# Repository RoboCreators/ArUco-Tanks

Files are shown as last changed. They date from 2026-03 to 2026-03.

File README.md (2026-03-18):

# ArUco Tanks

Ein kamerabasiertes Laser-Tag-Spielsystem mit ferngesteuerten ESP32-Fahrzeugen und markerbasierter Objekterkennung über ArUco-Marker.

Das Projekt wurde im Rahmen eines Studienprojekts an der **HTWK Leipzig** entwickelt.  
Die Treffererkennung erfolgt softwareseitig über eine externe Kamera, Computer Vision und eine zentrale Spiellogik auf dem Laptop.

<p align="center">
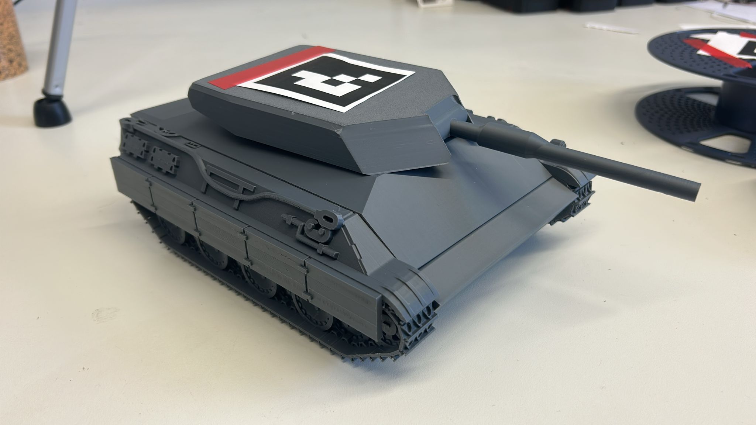
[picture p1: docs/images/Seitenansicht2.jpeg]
  
</p>

---

## Inhaltsverzeichnis

- [Zielsetzung](#zielsetzung)
- [Systemübersicht](#systemübersicht)
- [Hardwareübersicht](#hardwareübersicht)
- [Software- & Repository-Struktur](#software--repository-struktur)
- [Getting Started](#getting-started)
- [Projektkontext](#projektkontext)
- [Nützliche Ressourcen](#nützliche-ressourcen)
- [Weiterentwicklung](#weiterentwicklung)
- [Lizenz](#lizenz)

---

## Zielsetzung

Ziel des Projekts ist die Entwicklung eines spielbaren Mehrkomponentensystems aus:

- zwei ferngesteuerten Fahrzeugen
- einer externen Kamerainstanz zur Objekterkennung
- einer zentralen Spielumgebung auf dem Laptop
- einer softwarebasierten Treffererkennung mit ArUco-Markern

Dabei werden mechanische Konstruktion, Mikrocontrollersteuerung, drahtlose Kommunikation, Kamerakalibrierung und Bildverarbeitung in einem Gesamtsystem kombiniert.

---

## Systemübersicht

Das Spielsystem basiert auf einer **markerbasierten visuellen Objekterkennung**.

- Eine externe Kamera erfasst das Spielfeld.
- Die Fahrzeuge tragen ArUco-Marker zur Positions- und Orientierungserkennung.
- Ein Laptop übernimmt die Bildverarbeitung und Spiellogik.
- Die Kommunikation mit den Fahrzeugen erfolgt drahtlos über ESP32-basierte Steuerung.
- Treffer werden nicht durch physische Sensoren, sondern über die geometrische Auswertung von Schusslinie und Hitbox in der Spielumgebung erkannt.

---

## Hardwareübersicht

### Fahrzeuge

- ESP32 Dev Board  
- LM2596 Step-Down Converter
- 2× DC Getriebemotoren 
- 28BYJ-48 Schrittmotor  
- WS-25514 Motorcontroller  
- ULN2003 Treibermodul  
- 7.4 V Li-Ion Akku  
- Hauptschalter (DPDT)
- Reset-Button

### Externe Komponenten

- Kamera zur Erfassung des Spielfelds
- Laptop zur Bildverarbeitung und Spielsteuerung
- Gamepad zur Fahrzeugsteuerung

### Markerbasiertes Tracking

- ArUco-Marker zur Identifikation der Fahrzeuge
- Kamerakalibrierung zur präziseren Positionsbestimmung
- Berechnung von Position, Orientierung und Schussrichtung im Kamerabild

### Benötigte Verbindungselemente

Für den Aufbau werden zusätzlich folgende Schrauben, Muttern und Gewindeeinsätze benötigt:

- **M2:** 5× M2×6 mm, 2× M2×13 mm, 6× Muttern, 1× Heatset-Insert
- **M2.5:** 10× M2,5×10 mm, 10× Muttern
- **M3:** 18× M3×6 mm, 2× M3×8 mm, 1× M3×10 mm, 10× Muttern, 7× Heatset-Inserts
- **M4:** 2× M4×8 mm, 2× Heatset-Inserts
  
---

## Software & Repository-Struktur

Dieses Repository enthält die zentralen Software- und CAD-Dateien des Projekts.

### CAD

`Baugruppe ArUcoTank`

- Konstruktionsdaten der Fahrzeugkomponenten
- Gehäuse-, Turm- und Halterungsstrukturen
- Grundlage für mechanischen Aufbau und Anpassungen

### Arduino-Code

`Arduino_Steuerungscode.ino`

- Fahransteuerung der Fahrzeuge
- Verarbeitung der Steuerbefehle
- Kommunikation mit der Spielumgebung
- Ansteuerung der Fahrzeugfunktionen über den ESP32

### Jupyter-Notebooks

`01_marker_and_calibration.ipynb`

- Erstellung und Test von ArUco-Markern
- Kamerakalibrierung
- Vorbereitung der markerbasierten Positionsbestimmung

`02_esp32_connection.ipynb`

- Verbindungsaufbau zwischen Laptop und Fahrzeugen
- Kommunikationslogik
- Test der Netzwerkverbindung

`03_detection_and_game_logic.ipynb`

- Objekterkennung mit Kamera
- Bestimmung von Fahrzeugposition und Orientierung
- Trefferlogik, Schussauswertung und Spielmechanik

---

## Getting Started

Das zugehörige Git-Repository enthält neben dem Quellcode auch die mechanische Konstruktion, eine Montageanleitung sowie die Notebooks zur Spielumgebung und Kamerakalibrierung.

Die Montageanleitung befindet sich im Ordner docs.

### Voraussetzungen

Benötigt werden unter anderem:

- Python 3.x
- Jupyter Notebook
- OpenCV mit ArUco-Unterstützung
- NumPy
- ein ESP32-basiertes Fahrzeug
- eine geeignete Kamera
- optional ein Gamepad zur Steuerung

### Empfohlene Reihenfolge

1. ArUco-Marker erzeugen und Kamera kalibrieren  
2. Verbindung zum ESP32 testen  
3. Detektion und Spielumgebung starten  
4. Fahrzeuge im Kamerabild erfassen und Spiel testen  

---

## Projektkontext

Das Projekt entstand im Rahmen des Moduls  
**„Ausgewählte Themen der Automatisierungstechnik“**  
an der **HTWK Leipzig**.

Im Fokus standen insbesondere die Verknüpfung von:

- integrierte Steuerung
- drahtloser Kommunikation
- Computer Vision
- spielbezogener Systemintegration
- iterativer praktischer Entwicklung

---

## Nützliche Ressourcen

### OpenCV / ArUco

- OpenCV Dokumentation
- ArUco Marker Detection
- Kamerakalibrierung mit OpenCV

### ESP32

- ESP32 Dokumentation
- Arduino IDE / ESP32 Board Support

### Python / Notebook-Umgebung

- Jupyter Dokumentation
- NumPy Dokumentation

---

## Weiterentwicklung

Mögliche Erweiterungen des Systems:

- mehrere Kameras zur besseren Spielfeldabdeckung
- autonome Fahrfunktionen
- Erweiterung auf mehr als zwei Fahrzeuge
- verbesserte Benutzeroberfläche für Spielstatus und Punkteanzeige
- optimierte Netzwerkkommunikation und Synchronisation

---

## Projektteam

- Robert B.
- Hieu D.
- Jonas W.

## Lizenz

Dieses Projekt steht unter der **MIT License**.

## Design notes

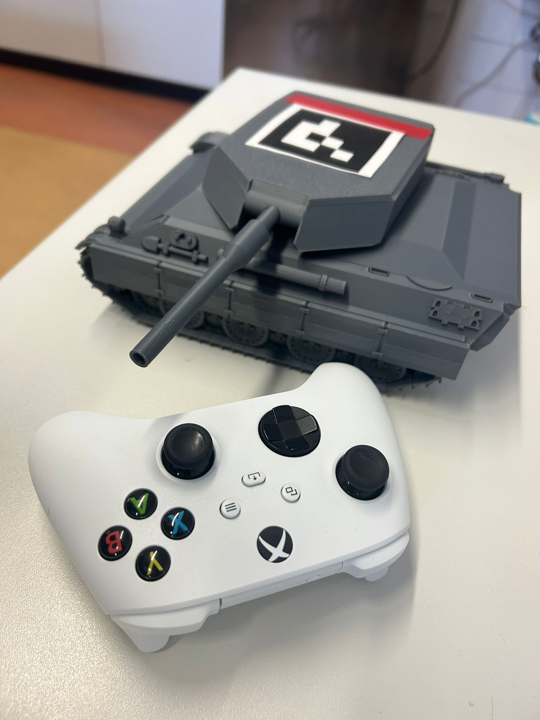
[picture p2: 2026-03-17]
docs/images/Panzer_Gamepad.jpeg

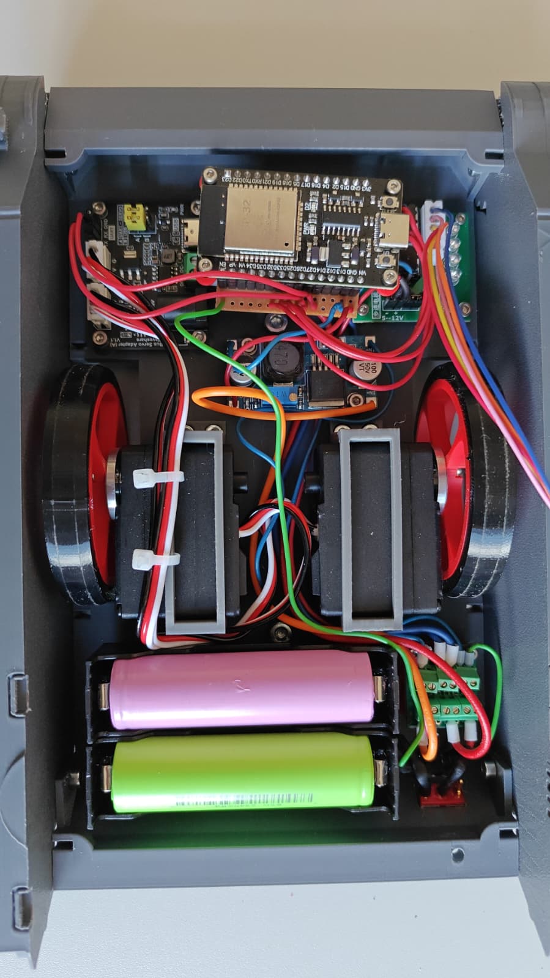
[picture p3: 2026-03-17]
docs/images/Innenraum.jpeg

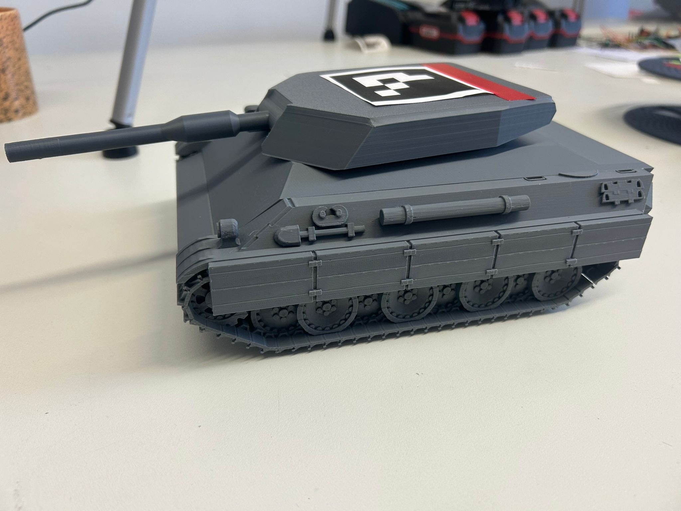
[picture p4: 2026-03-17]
docs/images/Seitenansicht.jpeg

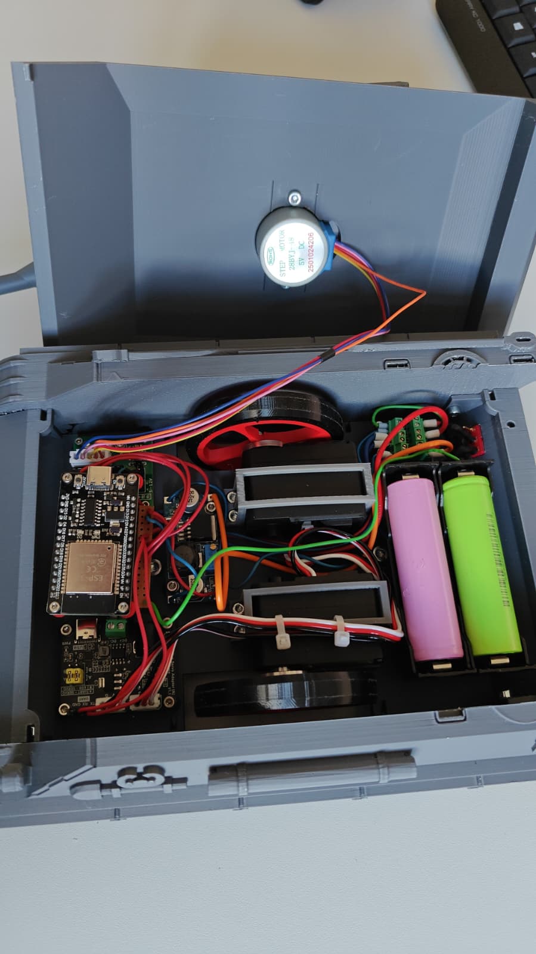
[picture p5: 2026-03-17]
docs/images/offener_Deckel.jpeg

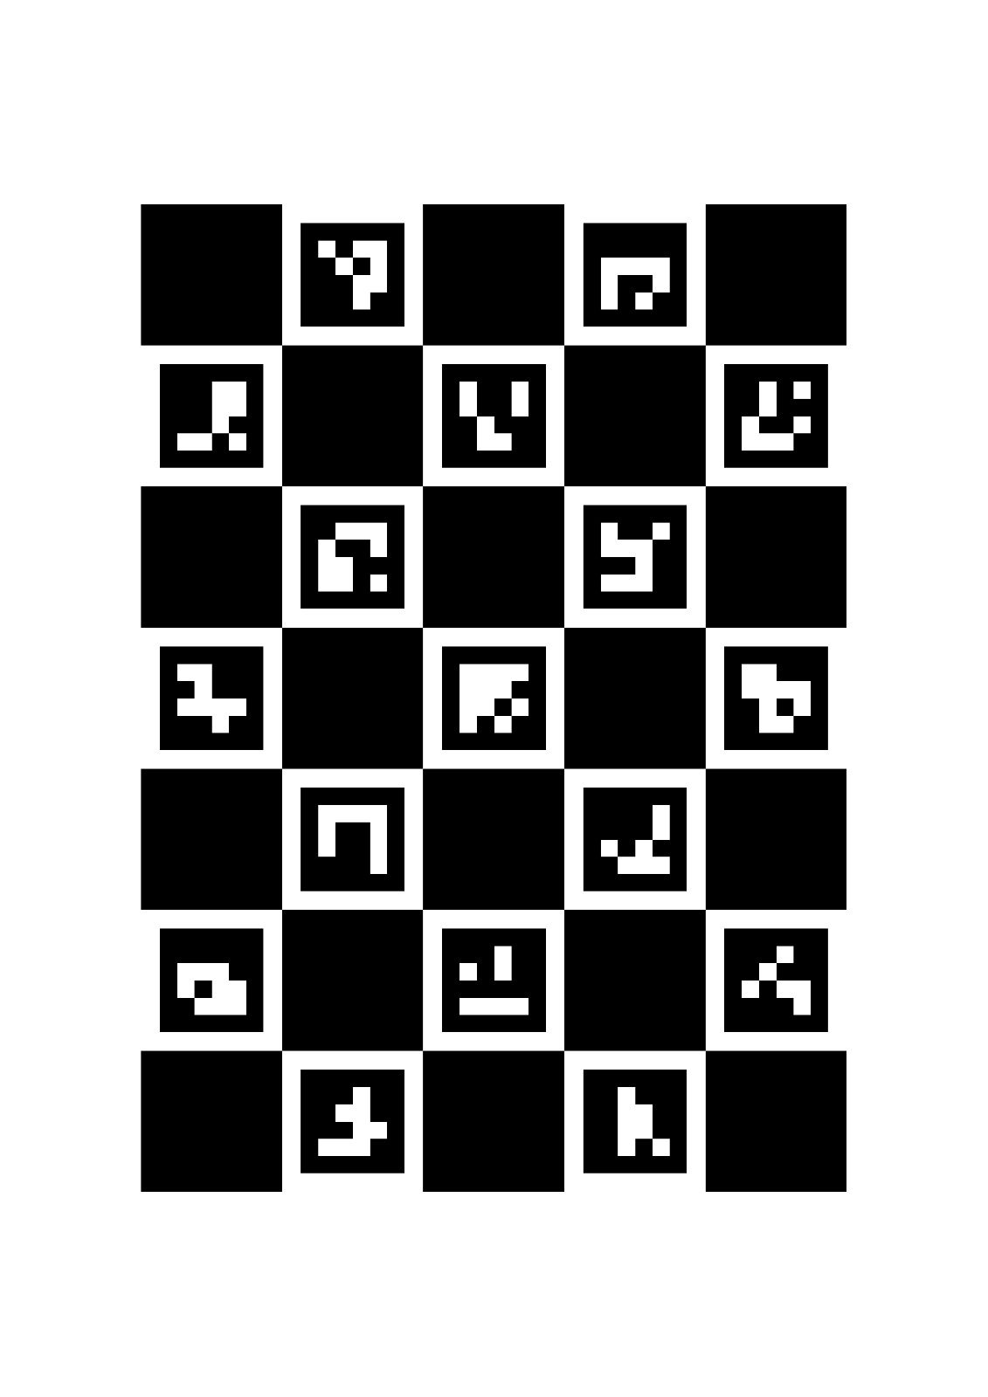
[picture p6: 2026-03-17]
docs/images/ArUco-Board.jpeg

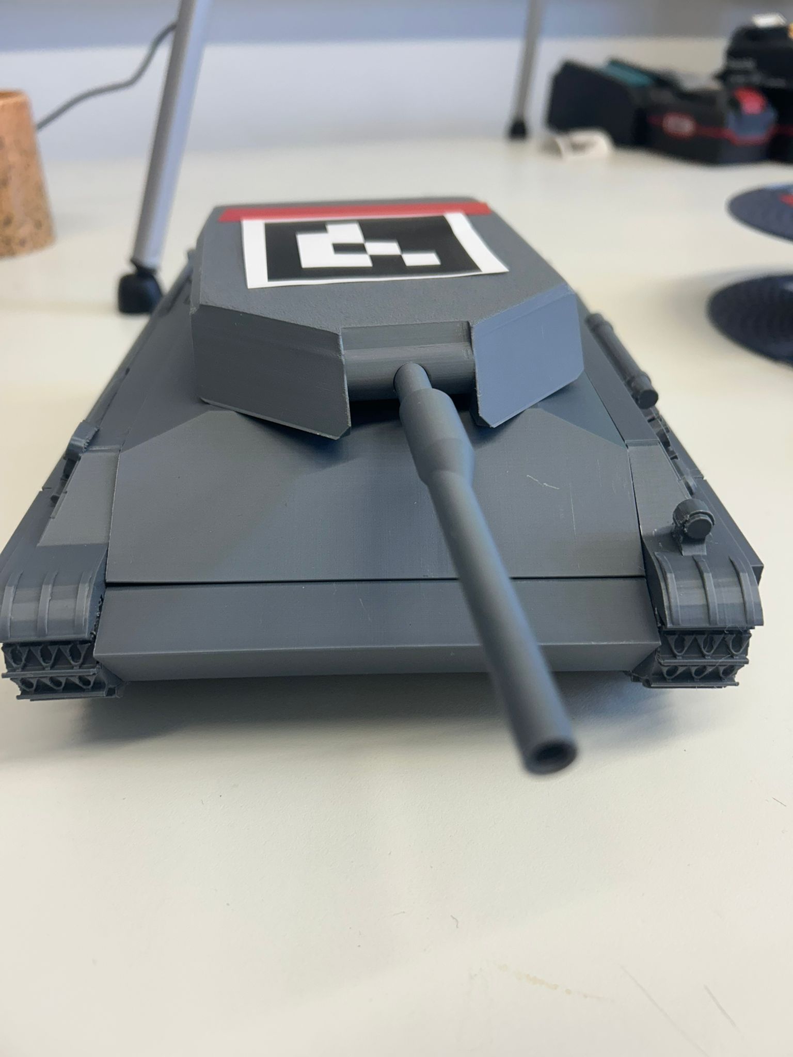
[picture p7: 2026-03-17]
docs/images/Frontansicht.jpeg

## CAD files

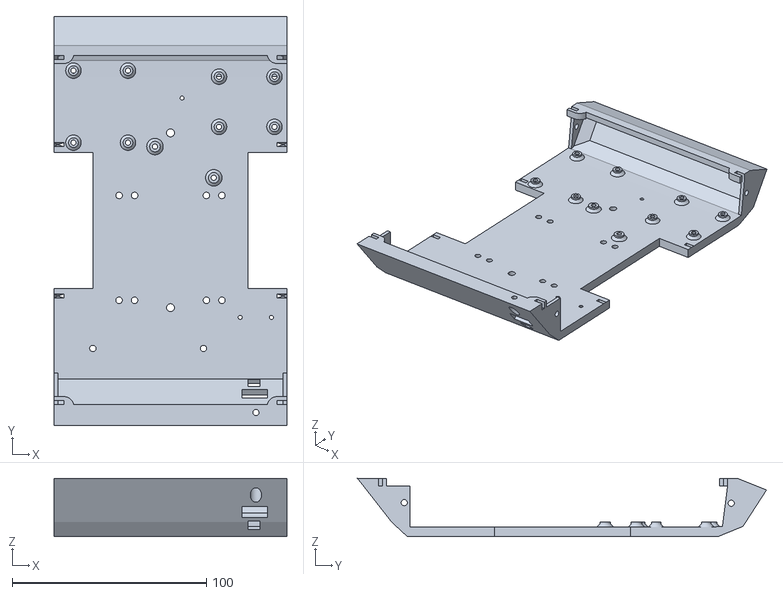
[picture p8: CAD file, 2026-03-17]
STL-Dateien/Gehäuseunterteil.stl
120.0 x 210.7 x 30.0

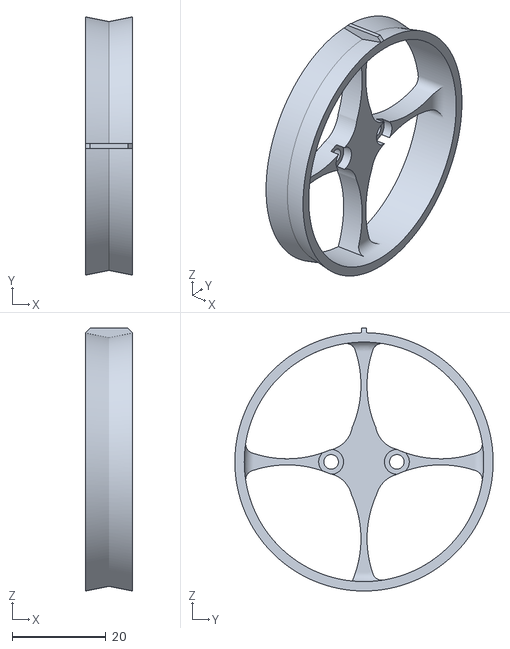
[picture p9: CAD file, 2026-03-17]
STL-Dateien/Rad.stl
10.0 x 55.0 x 56.0

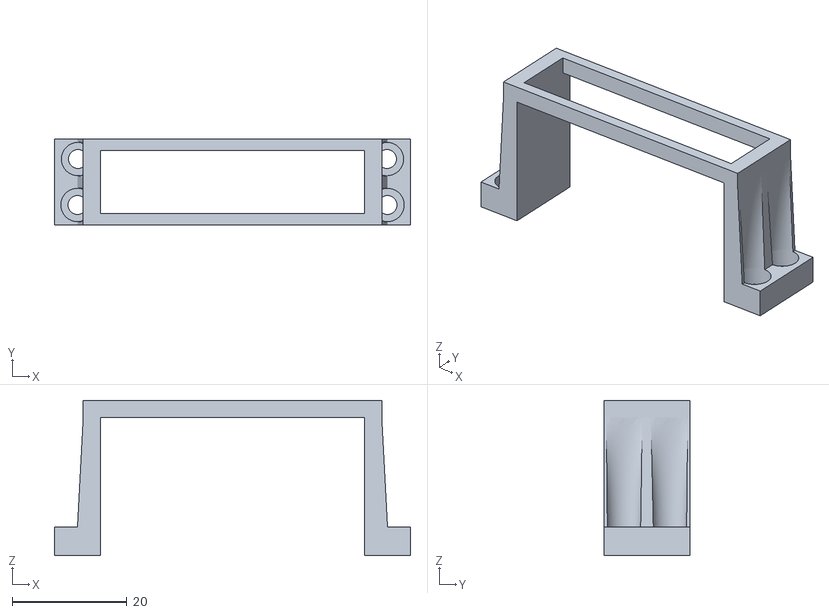
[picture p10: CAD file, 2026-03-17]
STL-Dateien/Servoklemme.stl
62.0 x 15.0 x 27.0

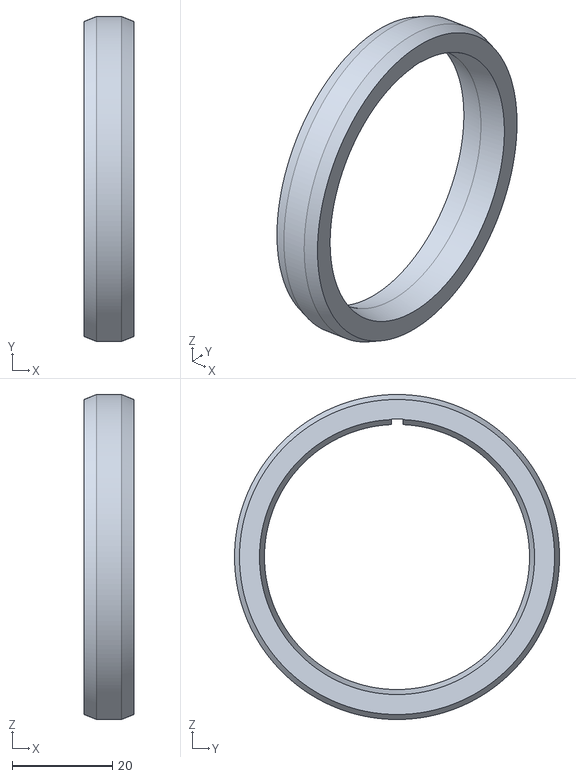
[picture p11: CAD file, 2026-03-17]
STL-Dateien/Reifen.stl
10.0 x 65.0 x 65.0

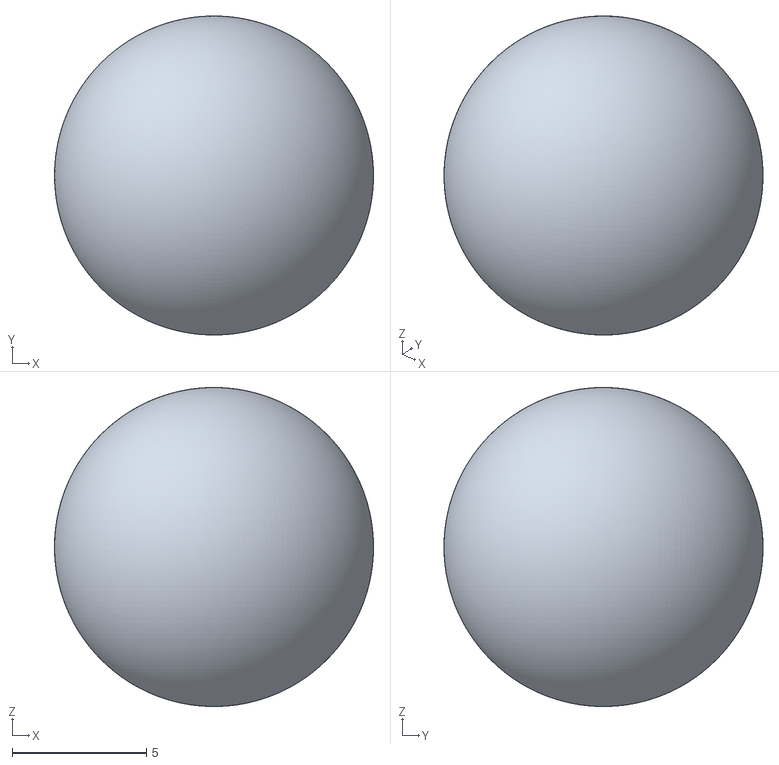
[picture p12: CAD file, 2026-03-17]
STL-Dateien/Kugel.stl
11.9 x 11.9 x 11.9

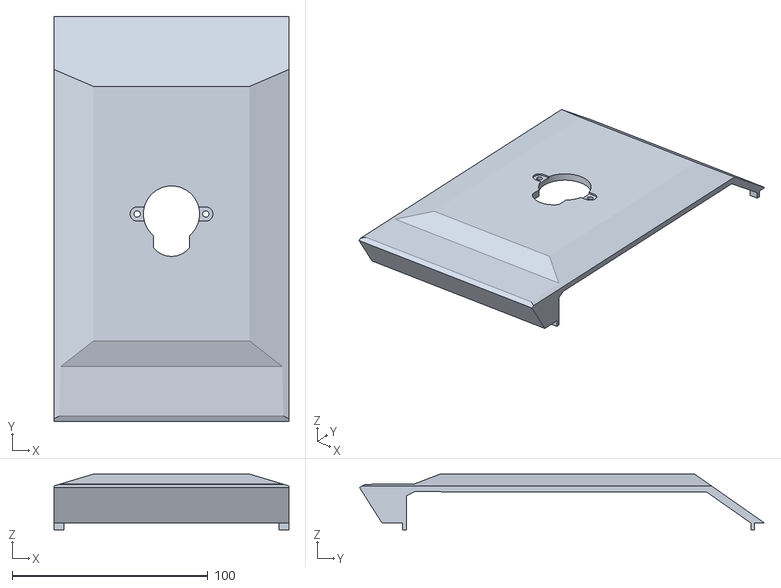
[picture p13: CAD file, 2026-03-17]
STL-Dateien/Gehäuseoberteil.stl
120.0 x 207.1 x 28.5

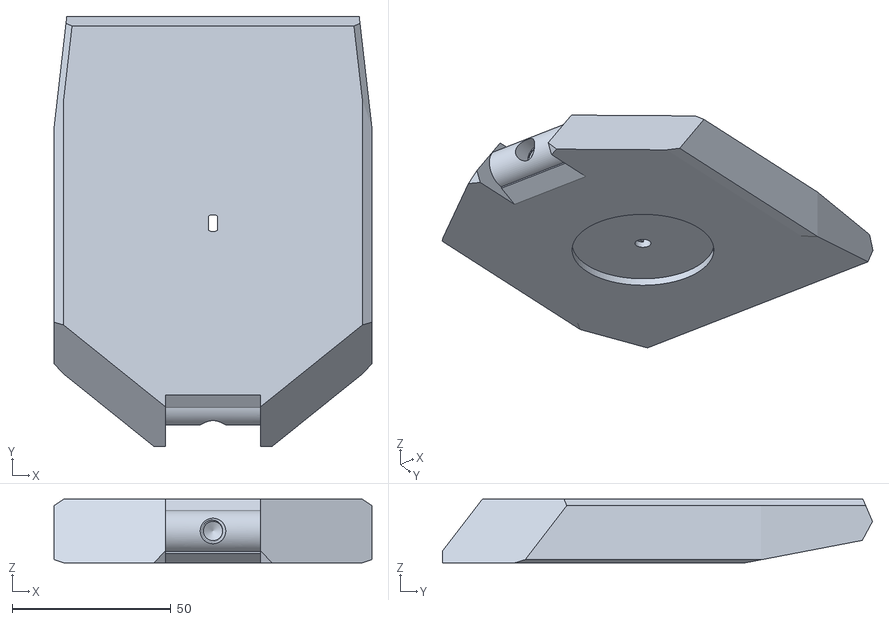
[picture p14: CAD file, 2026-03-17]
STL-Dateien/Panzerturm.stl
100.0 x 135.2 x 20.0

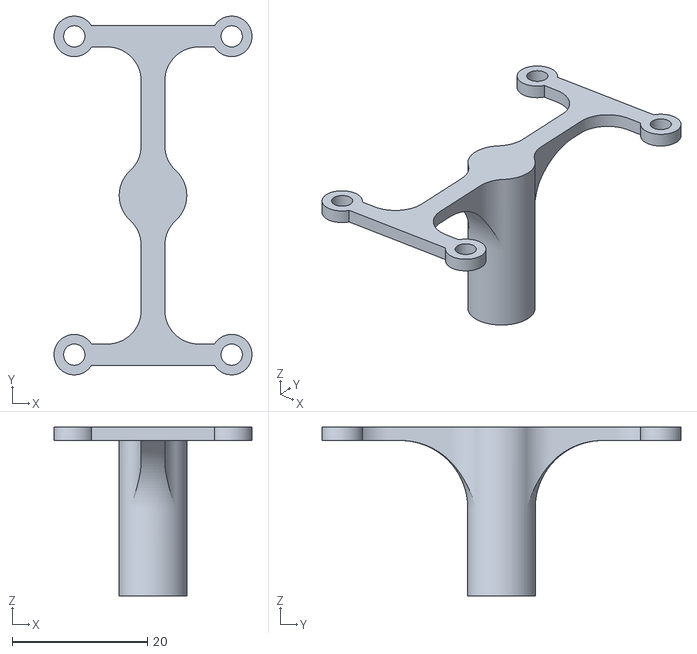
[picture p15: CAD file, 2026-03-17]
STL-Dateien/ESP32 Halter.stl
29.3 x 53.1 x 25.0

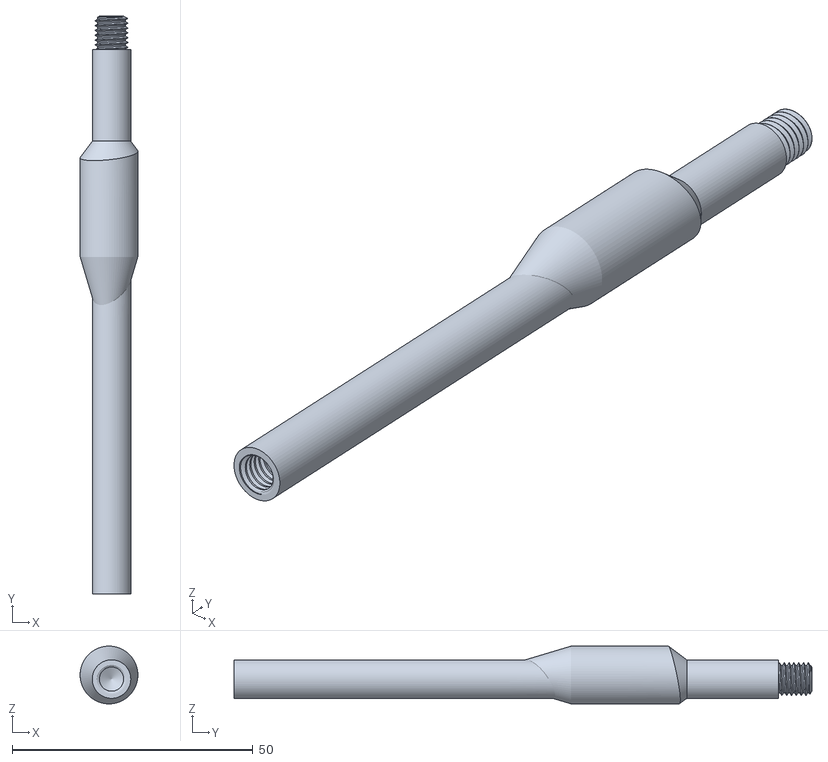
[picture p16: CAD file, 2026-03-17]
STL-Dateien/Kanone.stl
12.0 x 120.0 x 12.0

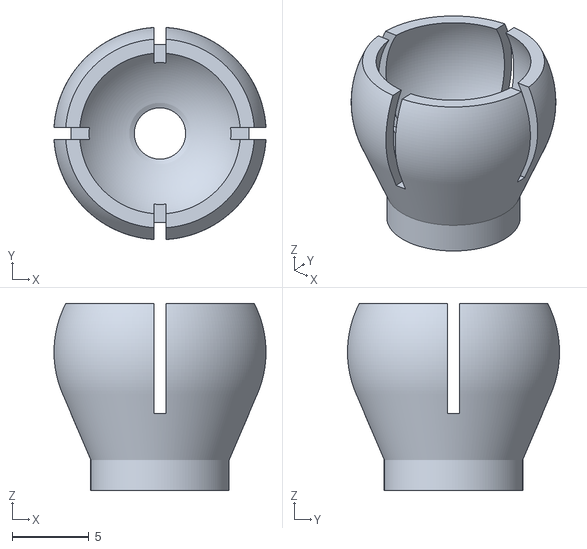
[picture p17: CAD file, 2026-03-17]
STL-Dateien/Kugelhalter.stl
13.8 x 13.8 x 12.2

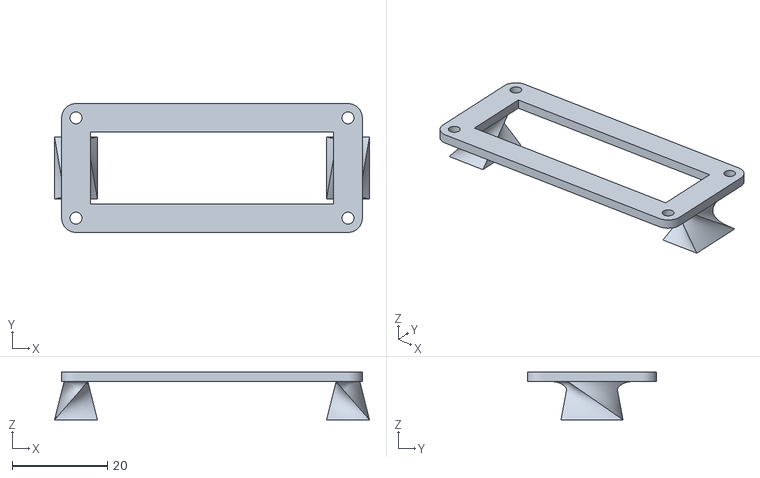
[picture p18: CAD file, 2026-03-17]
STL-Dateien/Batteriehalter.stl
66.0 x 27.0 x 10.0

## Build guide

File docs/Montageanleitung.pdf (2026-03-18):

15.03.2026

Montageanleitung ArUcoTank

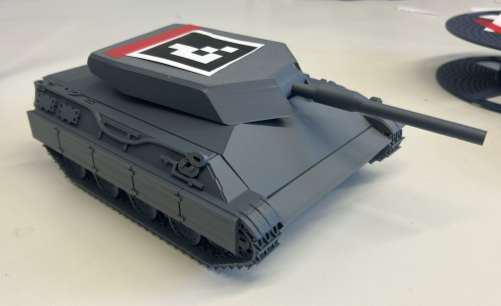
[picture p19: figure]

Alle Grundlochbohrungen werden mit den zugehörigen Heatset-inserts bei einer Lötkolbentemperatur von ca. 250°C bestückt.

Zunächst werden die Kugelhalter mit M3-Schrauben am Unterteil befestigt. Anschließend wird das ESP-Dev-Board mit M2-Schrauben am dafür vorgesehenen Halter montiert.

Im nächsten Schritt werden die Module auf die vorgesehenen Bohrungen auf die Noppen des Gehäuseunterteils aufgelegt und festgeschraubt: Hierzu zählen das ESP-Dev-Board mit Halter, der Bus-Servo-Treiber, der Schrittmotor-Treiber, der Step-Down-Wandler, die selbstgebaute Platine mit Anschlussklemmen.

Für die Befestigung des ESP-Dev-Boards mit Halter, der Platine mit Anschlussklemmen sowie der Step-Down-Wandler werden M2-Schrauben mit Muttern verwendet. Alle übrigen Module werden mit M3-Schrauben und Muttern befestigt.

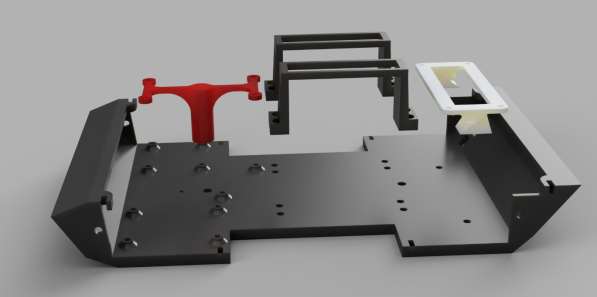
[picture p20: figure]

15.03.2026

Die zwei Reifen werden, formschlüssig mit der Nut, auf die Räder aufgezogen und an die Servomotoren geschraubt. Die Servomotoren wiederum mit den zwei Servoklemmen auf dem Gehäuseunterteil mittig befestigen.

Danach wird der Schalter und der mechanischer Taster in die vorgesehenen Einkerbungen am Gehäuseunterteil eingesetzt. Anschließend werden die beiden Panzerketten an den Eckwänden des Unterteils mit M3-Schrauben befestigt. Die Batteriehalterung wird mit M3-Schrauben auf der Hinterseite des Unterteils verschraubt und mit zwei 18650 Li-Ion Akkus bestückt.

Der Schrittmotor wird von oben durch das Gehäuseoberteil geführt und von unten mit 2 M3-Schrauben und Muttern fixiert. Die Kanone wird per Außengewinde und Passung in den Turm geschraubt und beides auf die Abtriebswelle des Schrittmotors gesteckt.

Abschließend wird das Oberteil mithilfe der vorgesehenen Einkerbungen auf dem Unterteil positioniert und mit einer Schraube an der Hinterseite fixiert. Zur Erkennung per ComputerVision kann ein ArUco-Marker auf die Turmoberseite geklebt werden.

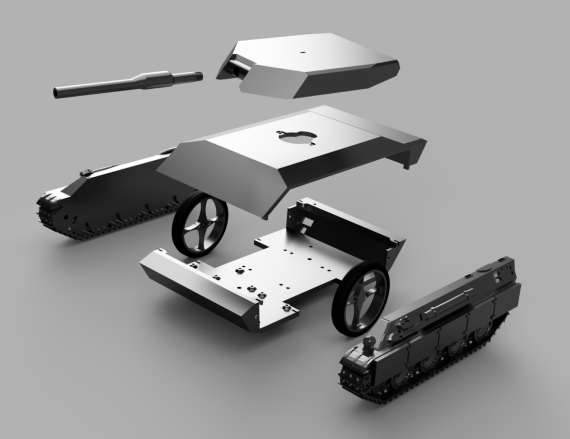
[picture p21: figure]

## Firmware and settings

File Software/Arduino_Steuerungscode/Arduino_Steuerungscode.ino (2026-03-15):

#include <WiFi.h>
#include <WiFiUdp.h>
#include <SCServo.h>

#define S_RXD 14
#define S_TXD 27

// -------------------- WLAN --------------------
const char* WIFI_SSID = "XXX"; //Hotsot-Name
const char* WIFI_PASS = "XXX"; //Hotspot-Passwort

WiFiUDP Udp;
const uint16_t RX_PORT = 4210;

// -------------------- Protokoll --------------------
const uint8_t MAGIC   = 0xA7;
const uint8_t VERSION = 1;
const uint8_t TANK_ID = 1;

// -------------------- Failsafe --------------------
const uint32_t FAILSAFE_MS = 300;
uint32_t lastPacketMs = 0;

// -------------------- Servo --------------------
SMS_STS st;
byte ID[2];

// -------------------- Stepper --------------------
int IN1 = 25;
int IN2 = 33;
int IN3 = 32;
int IN4 = 26;

// -------------------- Empfangenes Steuerkommando --------------------
int16_t axisY  = 0;   // vor/zurück
int16_t axisX  = 0;   // links/rechts fahren
int16_t axisRX = 0;   // Turm

#pragma pack(push, 1)
struct CtrlPacket {
  uint8_t magic;
  uint8_t version;
  uint8_t tank_id;
  uint8_t seq;
  int16_t axisY_be;
  int16_t axisX_be;
  int16_t axisRX_be;
};
#pragma pack(pop)

static_assert(sizeof(CtrlPacket) == 10, "Packet size mismatch");

// ------------------------------------------------------------
// Big-Endian -> ESP32-Format umwandeln
// ------------------------------------------------------------
int16_t swap16(int16_t v) {
  uint16_t u = (uint16_t)v;
  u = (u >> 8) | (u << 8);
  return (int16_t)u;
}

// ------------------------------------------------------------
// Hilfsfunktion: alles stoppen
// ------------------------------------------------------------
void stopAll() {
  // Stepper aus
  digitalWrite(IN1, LOW);
  digitalWrite(IN2, LOW);
  digitalWrite(IN3, LOW);
  digitalWrite(IN4, LOW);

  // Servos stoppen
  st.WriteSpe(1, 0);
  st.WriteSpe(2, 0);
}

// ------------------------------------------------------------
// UDP-Paket lesen
// ------------------------------------------------------------
bool readUdpPacket() {
  int len = Udp.parsePacket();
  if (len <= 0) return false;

  if (len != sizeof(CtrlPacket)) {
    while (Udp.available()) {
      Udp.read();
    }
    return false;
  }

  CtrlPacket pkt;
  int r = Udp.read((uint8_t*)&pkt, sizeof(pkt));
  if (r != sizeof(pkt)) return false;

  if (pkt.magic != MAGIC)   return false;
  if (pkt.version != VERSION) return false;
  if (pkt.tank_id != TANK_ID) return false;

  // Wichtig: Python sendet Big Endian ("!")
  axisY  = swap16(pkt.axisY_be);
  axisX  = swap16(pkt.axisX_be);
  axisRX = swap16(pkt.axisRX_be);

  lastPacketMs = millis();
  return true;
}

// ------------------------------------------------------------
// Setup
// ------------------------------------------------------------
void setup() {
  Serial.begin(1000000);
  Serial.println("ESP32 startet...");

  // Stepper Pins
  pinMode(IN1, OUTPUT);
  pinMode(IN2, OUTPUT);
  pinMode(IN3, OUTPUT);
  pinMode(IN4, OUTPUT);

  // Servo Setup
  Serial1.begin(1000000, SERIAL_8N1, S_RXD, S_TXD);
  st.pSerial = &Serial1;

  ID[0] = 1;
  ID[1] = 2;

  st.WheelMode(1);
  st.WheelMode(2);

  stopAll();

  // WLAN
  WiFi.mode(WIFI_STA);
  WiFi.setSleep(false);
  WiFi.begin(WIFI_SSID, WIFI_PASS);

  Serial.print("Verbinde mit WLAN");
  while (WiFi.status() != WL_CONNECTED) {
    delay(300);
    Serial.print(".");
  }

  Serial.println();
  Serial.println("WLAN verbunden");
  Serial.print("IP: ");
  Serial.println(WiFi.localIP());

  // UDP starten
  Udp.begin(RX_PORT);
  Serial.print("UDP lauscht auf Port ");
  Serial.println(RX_PORT);
}

// ------------------------------------------------------------
// Loop
// ------------------------------------------------------------
void loop() {
  readUdpPacket();

  // Failsafe: wenn keine aktuellen Pakete mehr kommen -> stoppen
  if (millis() - lastPacketMs > FAILSAFE_MS) {
    stopAll();
    delay(2);
    return;
  }

  // Debug-Ausgabe
  Serial.print("axisX: ");
  Serial.print(axisX);
  Serial.print("   axisY: ");
  Serial.print(axisY);
  Serial.print("   axisRX: ");
  Serial.println(axisRX);

  // ----------------------------------------------------------
  // Stepper-Steuerung für Turm
  // ----------------------------------------------------------
  if (axisRX > 100) {
    digitalWrite(IN1, HIGH); digitalWrite(IN2, LOW);  digitalWrite(IN3, LOW);  digitalWrite(IN4, LOW);
    delay(2);
    digitalWrite(IN1, LOW);  digitalWrite(IN2, HIGH); digitalWrite(IN3, LOW);  digitalWrite(IN4, LOW);
    delay(2);
    digitalWrite(IN1, LOW);  digitalWrite(IN2, LOW);  digitalWrite(IN3, HIGH); digitalWrite(IN4, LOW);
    delay(2);
    digitalWrite(IN1, LOW);  digitalWrite(IN2, LOW);  digitalWrite(IN3, LOW);  digitalWrite(IN4, HIGH);
    delay(2);
  }
  else if (axisRX < -100) {
    digitalWrite(IN1, HIGH); digitalWrite(IN2, LOW);  digitalWrite(IN3, LOW);  digitalWrite(IN4, LOW);
    delay(2);
    digitalWrite(IN1, LOW);  digitalWrite(IN2, LOW);  digitalWrite(IN3, LOW);  digitalWrite(IN4, HIGH);
    delay(2);
    digitalWrite(IN1, LOW);  digitalWrite(IN2, LOW);  digitalWrite(IN3, HIGH); digitalWrite(IN4, LOW);
    delay(2);
    digitalWrite(IN1, LOW);  digitalWrite(IN2, HIGH); digitalWrite(IN3, LOW);  digitalWrite(IN4, LOW);
    delay(2);
  }
  else {
    digitalWrite(IN1, LOW);
    digitalWrite(IN2, LOW);
    digitalWrite(IN3, LOW);
    digitalWrite(IN4, LOW);
  }

  // ----------------------------------------------------------
  // Servo-Steuerung Fahren
  // axisY = vor/zurück
  // axisX = links/rechts
  //st.WrireSpe(1) ist rechtes Rad mit >0 für vorwärts
  //st.WrireSpe(2) ist linkes Rad mit <0 für vorwärts
  // ----------------------------------------------------------
  if (axisY < -250) {
      if (axisX < 450 && axisX > -450){
        st.WriteSpe(1, 3400);
        st.WriteSpe(2, -3400);//vorwärts
        }
      else if (axisX < -450){
        st.WriteSpe(1, 3400);
        st.WriteSpe(2, -1700);//vorwärts-links
      }
      else if (axisX > 450){
        st.WriteSpe(1, 1700);
        st.WriteSpe(2, -3400);//vorwärts-rechts
      }
  }

    else if (axisY > 250){
      if (axisX < 450 && axisX > -450){
        st.WriteSpe(1, -3400);
        st.WriteSpe(2, 3400);//rückwärts
      }
      else if (axisX < -450){
        st.WriteSpe(1, -3400);
        st.WriteSpe(2, 1700);//rückwärts-links
      }
      else if (axisX > 450){
        st.WriteSpe(1, -1700);
        st.WriteSpe(2, 3400);//rückwärts-rechts
      }
    }
    else if (axisX > 500 && axisY < 250 && axisY > -250){
      st.WriteSpe(1, -1700);
      st.WriteSpe(2, -1700);//drehen rechts
      }
    else if (axisX < -500 && axisY < 250 && axisY > -250){
      st.WriteSpe(1, 1700);
      st.WriteSpe(2, 1700); //drehen links
      }
  else{
    st.WriteSpe(1, 0);
    st.WriteSpe(2, 0);
  }

  delay(2);
}
